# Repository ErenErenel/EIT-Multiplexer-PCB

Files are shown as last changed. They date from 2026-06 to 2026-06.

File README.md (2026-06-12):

# EIT Multiplexer PCB

EE499 Capstone Project — Low-power analog multiplexer board for Electrical Impedance Tomography (EIT).

## Overview

This board drives a 16-channel analog multiplexer (ADG1606) controlled by an RP2040 microcontroller. It is designed for EIT data acquisition, where the multiplexer selects electrode channels to inject current and measure voltage.

**Key ICs:**
- Raspberry Pi RP2040 — microcontroller
- ADG1606 — 16:1 analog multiplexer
- AP2112K — 5V to 3.3V LDO regulator
- LM27761 — negative voltage converter (for symmetric supply)

## Repository Structure

```
Hardware/         — KiCad project files (.kicad_pro, .kicad_sch, .kicad_pcb)
                    Custom footprint and symbol libraries bundled for portability
Production/
  Gerbers/        — Gerber files + drill files ready for PCB fabrication
  BOM/            — Bill of Materials (CSV and XLSX)
Docs/             — Schematic PDF, assembly drawing, component datasheets
```

## Opening the Design

1. Open **KiCad** (v7 or later)
2. Open `Hardware/EIT_Multiplexer.kicad_pro`
3. All custom libraries load automatically via relative paths — no manual configuration needed

## Fabrication

Gerber files are in `Production/Gerbers/`. The board is 2-layer FR4. Upload the contents of that folder (or `EIT_Multiplexer-job.gbrjob`) to your preferred PCB fab (JLCPCB, PCBWay, OSH Park, etc.).

## License

Hardware design files licensed under [CERN Open Hardware Licence v2 – Strongly Reciprocal (CERN-OHL-S)](LICENSE).

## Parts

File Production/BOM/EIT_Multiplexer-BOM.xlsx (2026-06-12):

EIT Multiplexer — Bill of Materials
Item | Qty | Reference | Value | Voltage | Size | Dielectric / Notes | Tolerance | Manufacturer | Manuf. Part # | Description
Resistors
1 | 2 | R1, R5 | 1kΩ |  | 0402 |  | 1% | Yageo | RC0402FR-071KP | RES SMD 1K OHM 1% 1/16W 0402
2 | 2 | R2, R6 | 10kΩ |  | 0402 |  | 1% | Yageo | RC0402FR-0710KP | RES SMD 10K OHM 1% 1/16W 0402
3 | 2 | R3, R4 | 27Ω |  | 0402 |  | 1% | Yageo | RC0402FR-0727RL | RES SMD 27 OHM 1% 1/16W 0402
4 | 2 | R_INVERT1, R_INVERT2 | TBD |  | 0805 |  |  |  |  | Invert resistors — value TBD
Capacitors
5 | 2 | C2, C3 | 15pF | 50V | 0402 | C0G | 5% | Murata | GCM1555C1H150JA16D | CAP CER 15PF 50V C0G/NP0 0402
6 | 10 | C5,C6,C7,C9,C11,C12,C13,C14,C15,C16 | 100nF | 25V | 0402 | X7R | 10% | Murata | GRM155R71E104KE14J | CAP CER 0.1UF 25V X7R 0402
7 | 2 | C8, C10 | 1µF | 10V | 0402 | X6S | 10% | Murata | GRM155C81A105KA12D | CAP CER 1UF 10V X6S 0402
8 | 2 | C1, C4 | 10µF | 16V | 0805 | X5R | 10% | Murata | GRM21BR61C106KE15K | CAP CER 10UF 16V X5R 0805
9 | 8 | C17,C22,C23,C24,C25,C26,C27,C28 | 100nF | 25V | 0805 | X7R | 10% |  |  | CAP CER 0.1UF 25V X7R 0805 — bypass for mux ICs
10 | 2 | C18, C20 | 4.7µF | 10V | 0805 | X5R | 10% |  |  | CAP CER 4.7UF 10V X5R 0805
11 | 1 | C19 | 1µF | 16V | 0805 | X5R | 10% |  |  | CAP CER 1UF 16V X5R 0805
12 | 1 | C21 | 2.2µF | 10V | 0805 | X5R | 10% |  |  | CAP CER 2.2UF 10V X5R 0805
ICs
13 | 1 | U1 | NCP1117-3.3 |  | SOT-223-3 |  |  | ON Semiconductor | NCP1117ST33T3G | IC REG LINEAR 3.3V 1A SOT223
14 | 1 | U2 | W25Q128JVS |  | SOIC-8 |  |  | Winbond | W25Q128JVSIQ TR | IC FLASH 128M SPI 133MHZ 8SOIC
15 | 1 | U3 | RP2040 |  | QFN-56 |  |  | Raspberry Pi | RP2040 | MCU ARM Cortex-M0+ dual-core 133MHz QFN56
16 | 1 | U4 | LM27761DSGR |  | DSG-8 |  |  | Texas Instruments | LM27761DSGR | IC CONV DC/DC NEG 200MA 8WSON
17 | 4 | U5, U6, U7, U8 | ADG1606BCPZ-REEL7 |  | CP-32-2 |  |  | Analog Devices | ADG1606BCPZ-REEL7 | IC MUX 16:1 SINGLE 32LFCSP
Crystal
18 | 1 | Y1 | 12MHz ABM8-272-T3 |  | SMD 3225 |  |  | Abracon | ABM8-272-T3 | CRYSTAL 12.0000MHZ 3.2x2.5MM SMD
Connectors
19 | 1 | J1 | USB Micro-B |  |  |  |  | Amphenol | 10103594-0001LF | CONN RCPT USB2.0 MICRO B SMD R/A
20 | 1 | J2 | 1x16 pin socket |  | 2.54mm |  |  |  |  | Pin socket 1x16 2.54mm vertical
Switches
21 | 2 | SW1, SW2 | Pushbutton |  |  |  |  |  |  | Tactile push button SMD
Test Points
22 | 8 | GND(x4), I+, I-, V+, V- | Test Point |  | THT D2mm |  |  |  |  | THT test point pad D2.0mm drill 1.0mm
Mechanical
23 | 4 | H1, H2, H3, H4 | Mounting Hole |  | M2.5 |  |  |  |  | Mounting hole M2.5

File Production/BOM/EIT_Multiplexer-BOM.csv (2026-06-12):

Id | Designator | Footprint | Quantity | Designation | Supplier and ref
1 | R_INVERT2,R_INVERT1 | R_0805_2012Metric | 2 | R
2 | GND,I+,GND,I-,GND,V+,GND,V- | TestPoint_THTPad_D2.0mm_Drill1.0mm | 8 | Conn_01x01_Pin
3 | C4,C1 | C_0805_2012Metric | 2 | 10u
4 | J1 | USB_Micro-B_Amphenol_10103594-0001LF_Horizontal_modified | 1 | USB_B_Micro
5 | C10,C8 | C_0402_1005Metric | 2 | 1u
6 | C13,C5,C9,C12,C14,C7,C11,C16,C6,C15 | C_0402_1005Metric | 10 | 100n
7 | R2,R6 | R_0402_1005Metric | 2 | 10k
8 | U1 | SOT-223-3_TabPin2 | 1 | NCP1117-3.3_SOT223
9 | U2 | SOIC-8_5.3x5.3mm_P1.27mm | 1 | W25Q128JVS
10 | R1,R5 | R_0402_1005Metric | 2 | 1k
11 | R3,R4 | R_0402_1005Metric | 2 | 27
12 | U3 | RP2040-QFN-56 | 1 | RP2040
13 | U4 | DSG0008A | 1 | LM27761DSGR
14 | C18,C20 | C_0805_2012Metric | 2 | 4.7u
15 | C23,C26,C22,C25,C24,C28,C17,C27 | C_0805_2012Metric | 8 | 100n
16 | H3,H2,H4,H1 | MountingHole_2.7mm_M2.5 | 4 | MountingHole
17 | C2,C3 | C_0402_1005Metric | 2 | 15p
18 | C21 | C_0805_2012Metric | 1 | 2.2u
19 | C19 | C_0805_2012Metric | 1 | 1u
20 | SW2,SW1 | pushbutton (1) | 2 | SW_Push
21 | Y1 | Crystal_SMD_3225-4Pin_3.2x2.5mm | 1 | ABM8-272-T3
22 | U8,U7,U5,U6 | CP_32_2_ADI | 4 | ADG1606BCPZ-REEL7
23 | J2 | PinSocket_1x16_P2.54mm_Vertical | 1 | Conn_01x16_Pin

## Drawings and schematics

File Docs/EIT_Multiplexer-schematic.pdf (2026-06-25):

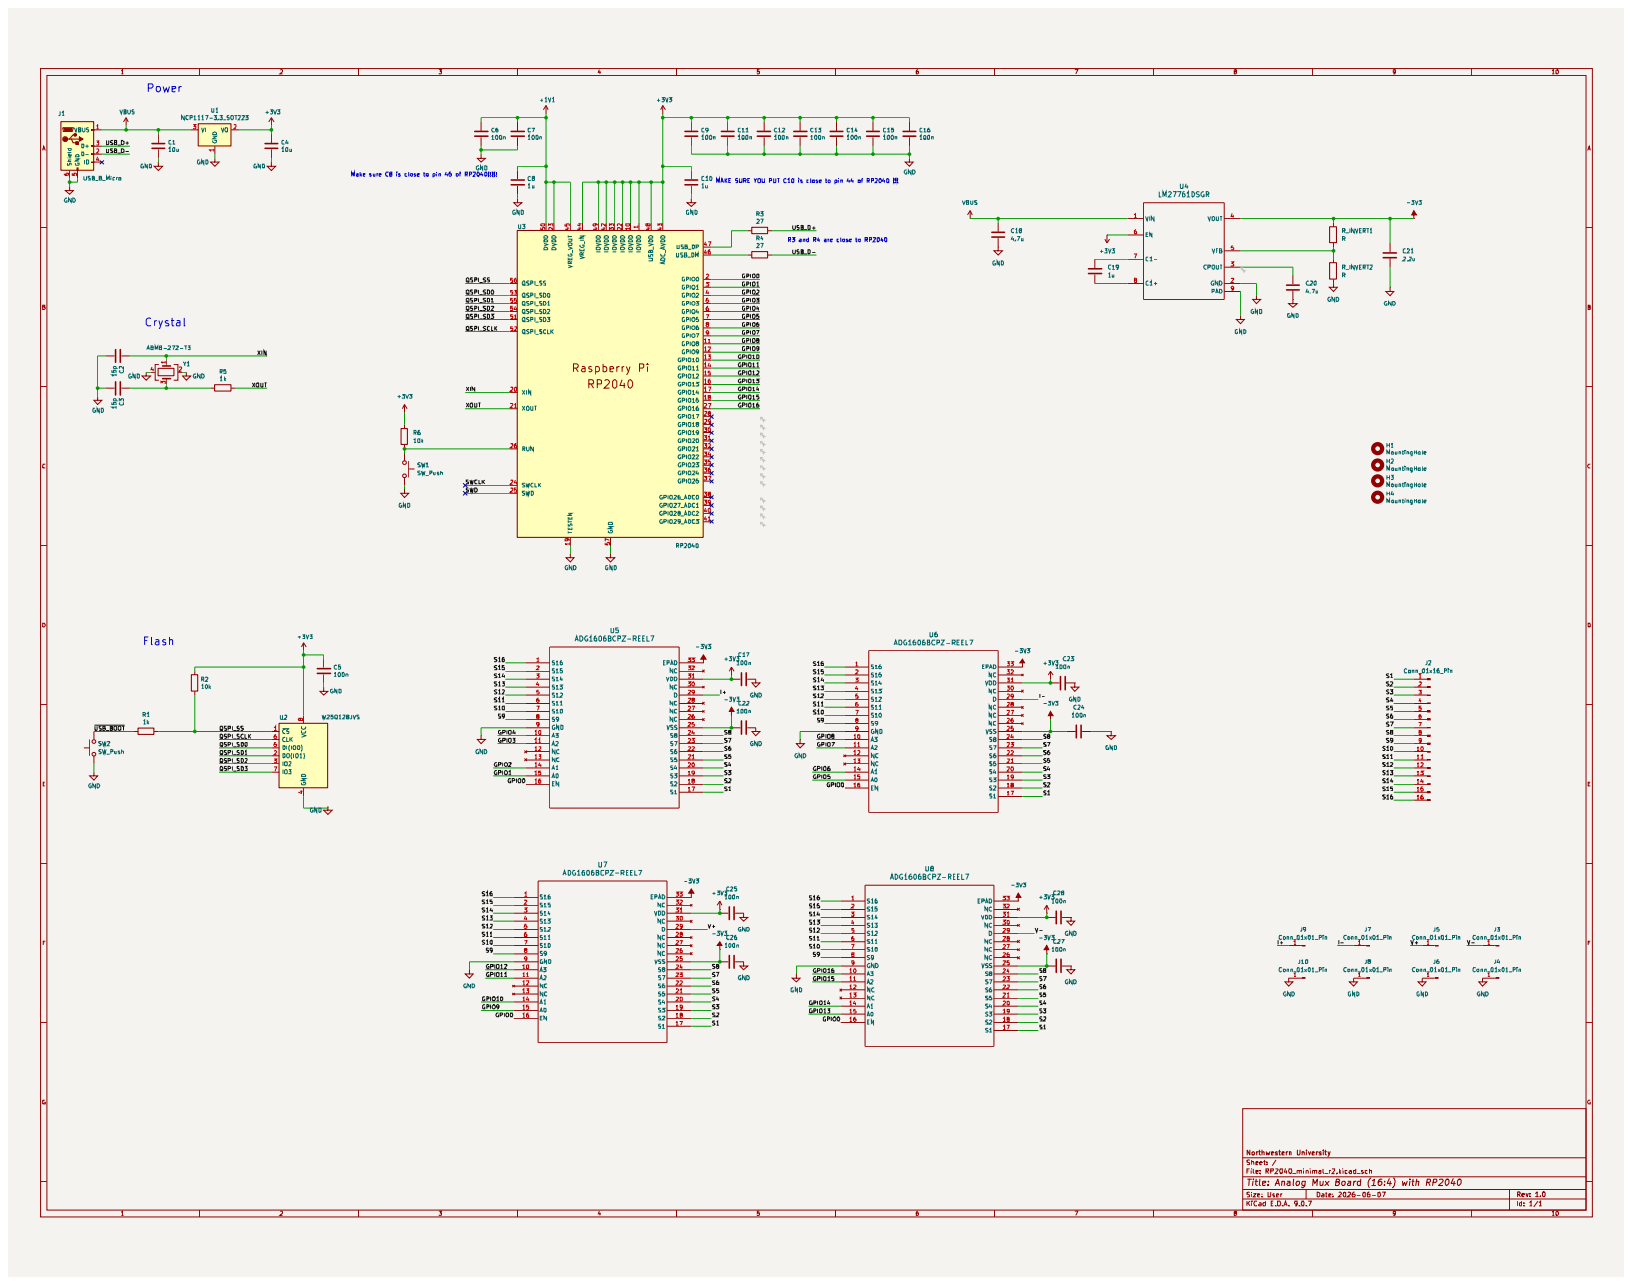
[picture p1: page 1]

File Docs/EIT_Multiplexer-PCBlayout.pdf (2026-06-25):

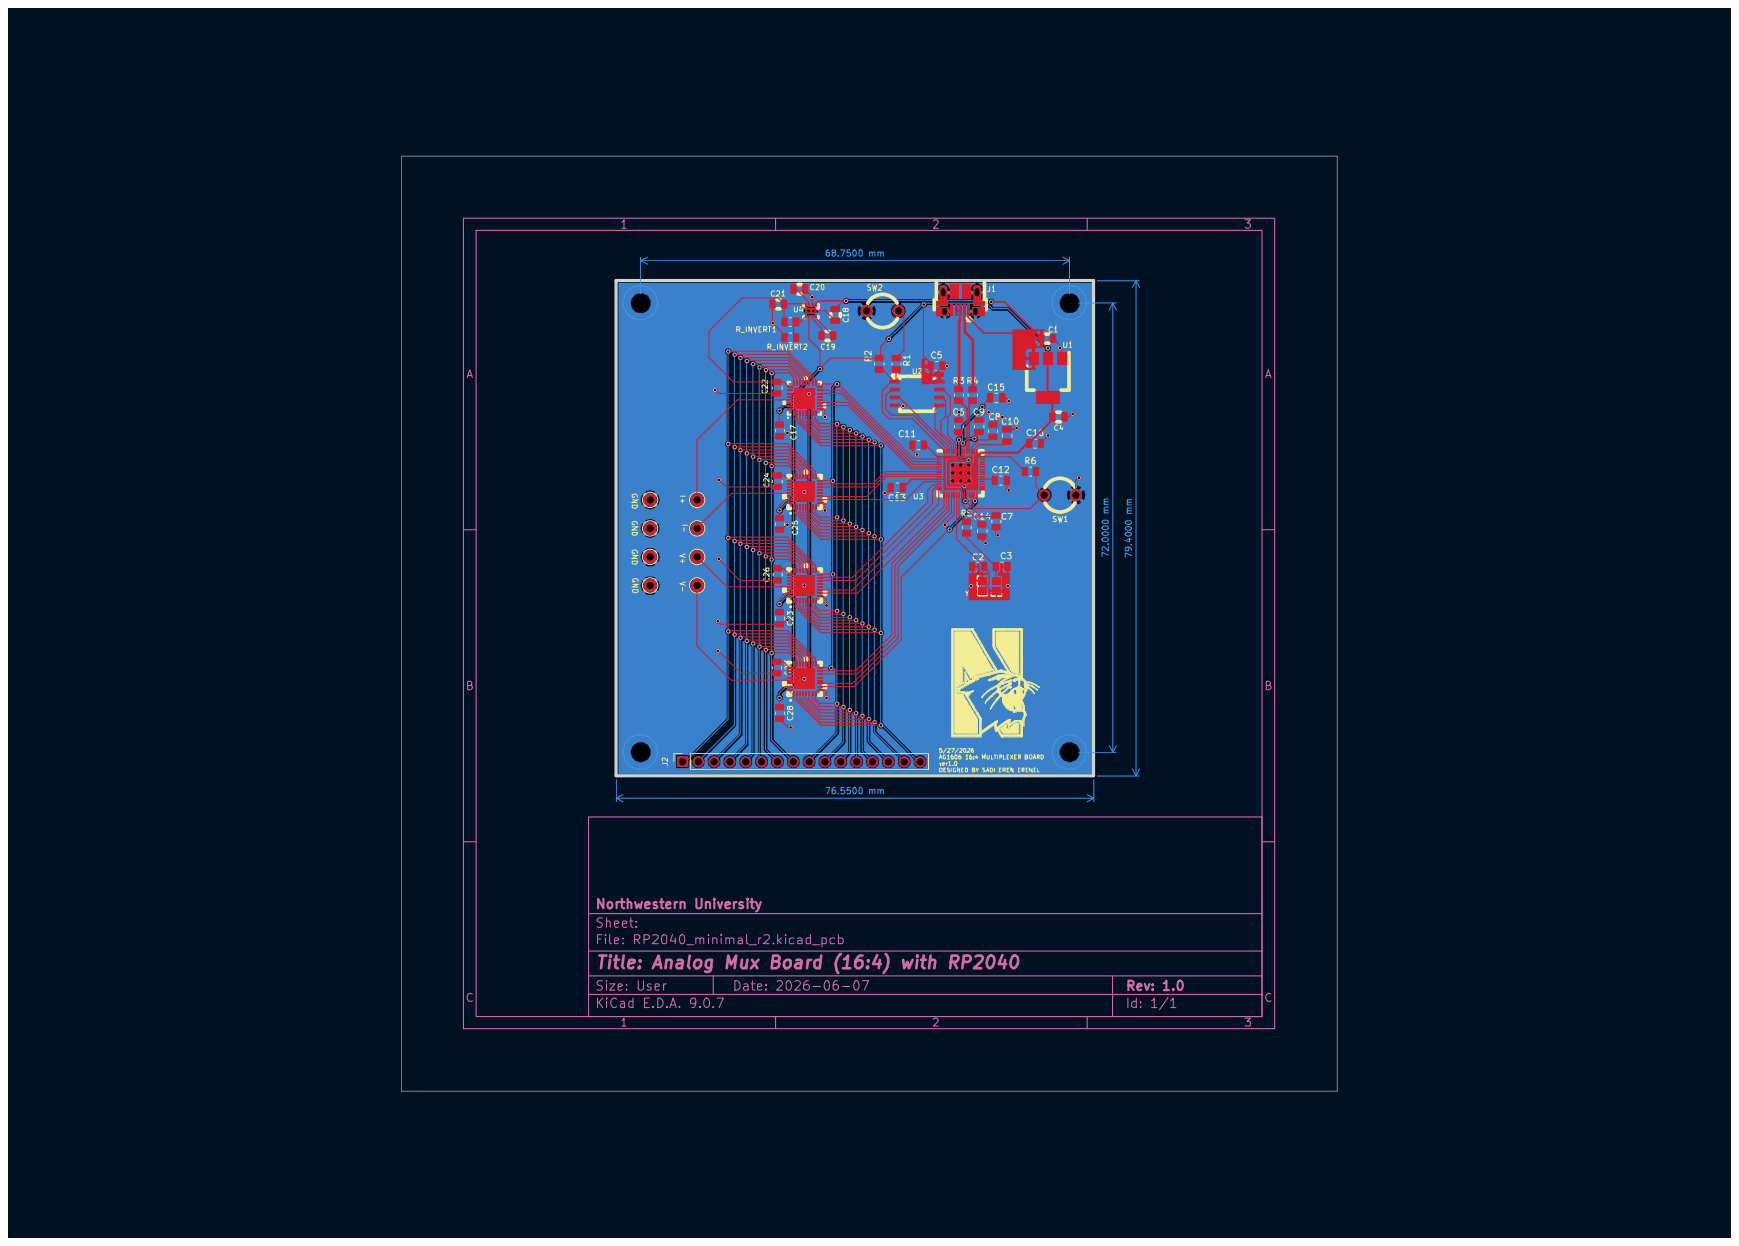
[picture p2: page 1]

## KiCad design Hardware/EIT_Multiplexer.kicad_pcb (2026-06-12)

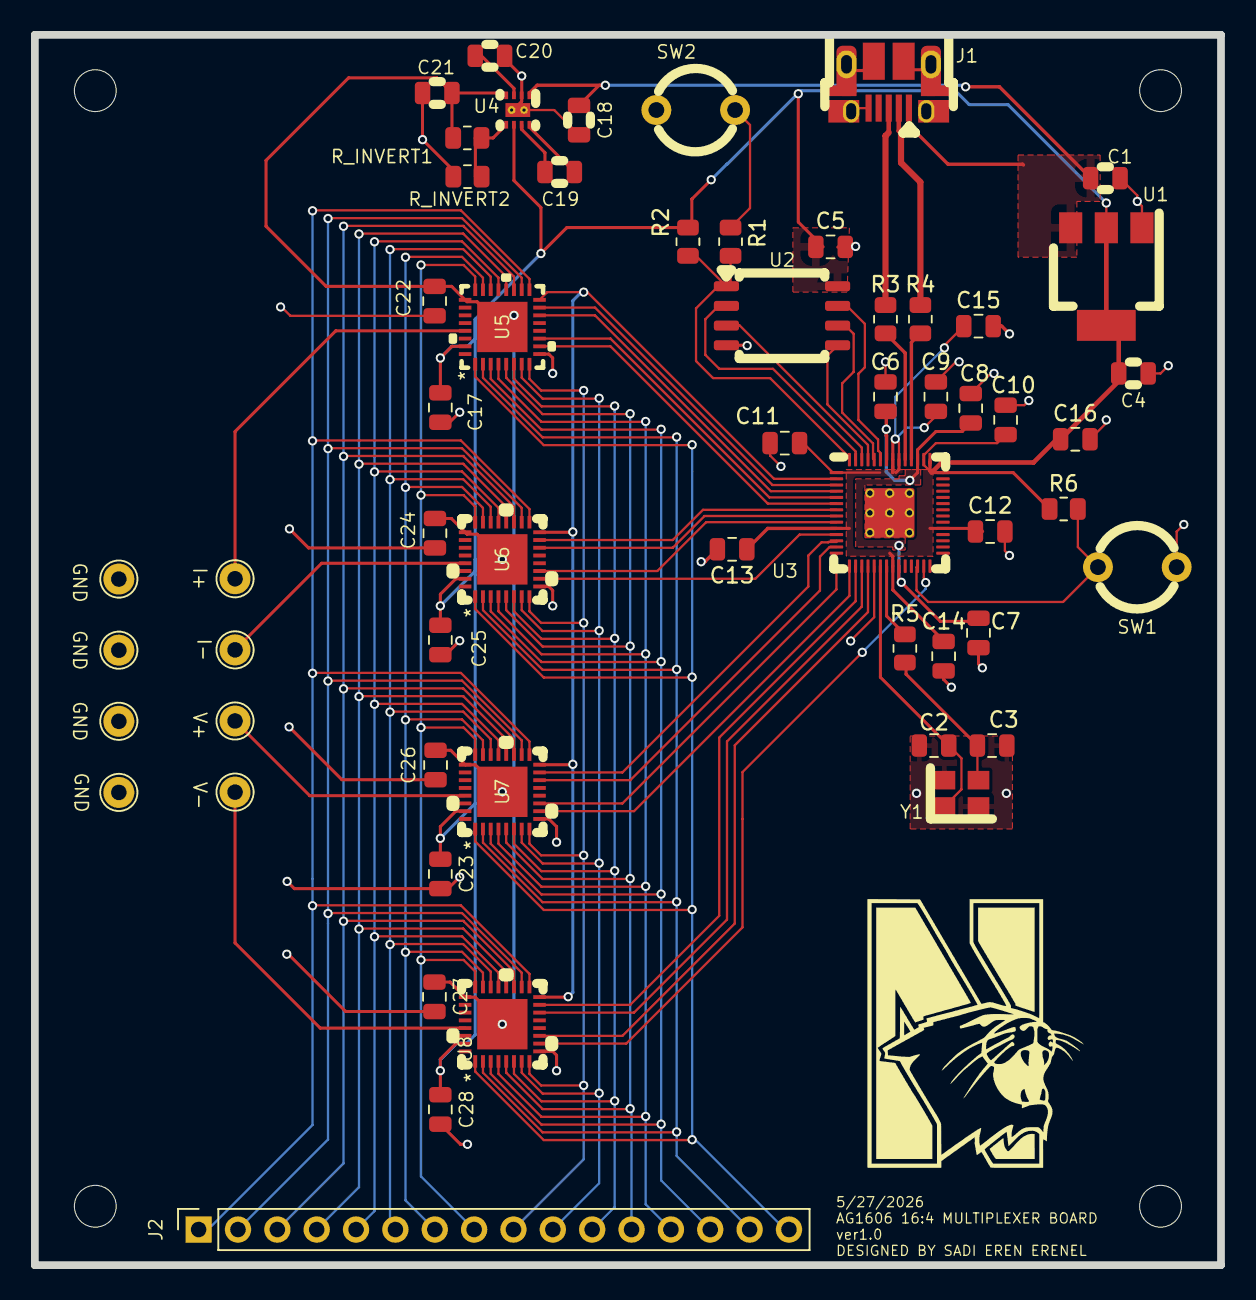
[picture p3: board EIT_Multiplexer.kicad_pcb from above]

Board: 2 copper layers, 76.5 x 79.4 mm, 61 parts (0 on the bottom side), 61 nets.

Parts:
C1, C4: 10u; C_0805_2012Metric
C2, C3: 15p; C_0805_2012Metric
C5, C6, C7, C9, C11, C12, C13, C14, C15, C16, C17, C22, C23, C24, C25, C26, C27, C28: 100n; C_0805_2012Metric
C8, C10, C19: 1u; C_0805_2012Metric
C18, C20: 4.7u; C_0805_2012Metric
C21: 2.2u; C_0805_2012Metric
GND: Conn_01x01_Pin; TestPoint_THTPad_D2.0mm_Drill1.0mm
GND#2, GND#3, GND#4: Conn_01x01_Pin; TestPoint_THTPad_D2.0mm_Drill1.0mm
H1, H2, H3, H4: MountingHole; MountingHole_2.7mm_M2.5
I+: Conn_01x01_Pin; TestPoint_THTPad_D2.0mm_Drill1.0mm
I-: Conn_01x01_Pin; TestPoint_THTPad_D2.0mm_Drill1.0mm
J1: USB_B_Micro; USB_Micro-B_Amphenol_10103594-0001LF_Horizontal_modified
J2: Conn_01x16_Pin; PinSocket_1x16_P2.54mm_Vertical
R1, R5: 1k; R_0805_2012Metric
R2, R6: 10k; R_0805_2012Metric
R3, R4: 27; R_0805_2012Metric
R_INVERT1, R_INVERT2: R; R_0805_2012Metric
SW1, SW2: SW_Push; pushbutton (1)
U1: NCP1117-3.3_SOT223; SOT-223-3_TabPin2
U2: W25Q128JVS; SOIC-8_5.3x5.3mm_P1.27mm
U3: RP2040; RP2040-QFN-56
U4: LM27761DSGR; DSG0008A
U5, U6, U7, U8: ADG1606BCPZ-REEL7; CP_32_2_ADI
V+: Conn_01x01_Pin; TestPoint_THTPad_D2.0mm_Drill1.0mm
V-: Conn_01x01_Pin; TestPoint_THTPad_D2.0mm_Drill1.0mm
Y1: ABM8-272-T3; Crystal_SMD_3225-4Pin_3.2x2.5mm

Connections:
+1V1: C6.1, C7.1, C8.1, U3.23 (DVDD), U3.45 (VREG_VOUT), U3.50 (DVDD)
+3V3: C4.1, C5.1, C9.1, C10.1, C11.1, C12.1, C13.1, C14.1, C15.1, C16.1, C17.1, C23.1, C25.1, C28.1, R2.1, R6.1, U1.2 (VO), U2.8 (VCC), U3.1 (IOVDD), U3.10 (IOVDD), U3.22 (IOVDD), U3.33 (IOVDD), U3.42 (IOVDD), U3.43 (ADC_AVDD), U3.44 (VREG_IN), U3.48 (USB_VDD), U3.49 (IOVDD), U4.6 (EN), U5.31 (VDD), U6.31 (VDD), U7.31 (VDD), U8.31 (VDD)
-3V3: C21.1, C22.1, C24.1, C26.1, C27.1, R_INVERT1.1, U4.4 (VOUT), U5.25 (VSS), U5.33 (EPAD), U6.25 (VSS), U6.33 (EPAD), U7.25 (VSS), U7.33 (EPAD), U8.25 (VSS), U8.33 (EPAD)
/GPIO0: U3.2 (GPIO0), U5.16 (EN), U6.16 (EN), U7.16 (EN), U8.16 (EN)
/GPIO1: U3.3 (GPIO1), U5.15 (A0)
/GPIO2: U3.4 (GPIO2), U5.14 (A1)
/GPIO3: U3.5 (GPIO3), U5.11 (A2)
/GPIO4: U3.6 (GPIO4), U5.10 (A3)
/GPIO5: U3.7 (GPIO5), U6.15 (A0)
/GPIO6: U3.8 (GPIO6), U6.14 (A1)
/GPIO7: U3.9 (GPIO7), U6.11 (A2)
/GPIO8: U3.11 (GPIO8), U6.10 (A3)
/GPIO9: U3.12 (GPIO9), U7.15 (A0)
/GPIO10: U3.13 (GPIO10), U7.14 (A1)
/GPIO11: U3.14 (GPIO11), U7.11 (A2)
/GPIO12: U3.15 (GPIO12), U7.10 (A3)
/GPIO13: U3.16 (GPIO13), U8.15 (A0)
/GPIO14: U3.17 (GPIO14), U8.14 (A1)
/GPIO15: U3.18 (GPIO15), U8.11 (A2)
/GPIO16: U3.27 (GPIO16), U8.10 (A3)
/I+: I+.1, U5.29 (D)
/I-: I-.1, U6.29 (D)
/QSPI_SCLK: U2.6 (CLK), U3.52 (QSPI_SCLK)
/QSPI_SD0: U2.5 (DI(IO0)), U3.53 (QSPI_SD0)
/QSPI_SD1: U2.2 (DO(IO1)), U3.55 (QSPI_SD1)
/QSPI_SD2: U2.3 (IO2), U3.54 (QSPI_SD2)
/QSPI_SD3: U2.7 (IO3), U3.51 (QSPI_SD3)
/QSPI_SS: R1.1, R2.2, U2.1 (~CS), U3.56 (QSPI_SS)
/S1: J2.1, U5.17 (S1), U6.17 (S1), U7.17 (S1), U8.17 (S1)
/S2: J2.2, U5.18 (S2), U6.18 (S2), U7.18 (S2), U8.18 (S2)
/S3: J2.3, U5.19 (S3), U6.19 (S3), U7.19 (S3), U8.19 (S3)
/S4: J2.4, U5.20 (S4), U6.20 (S4), U7.20 (S4), U8.20 (S4)
/S5: J2.5, U5.21 (S5), U6.21 (S5), U7.21 (S5), U8.21 (S5)
/S6: J2.6, U5.22 (S6), U6.22 (S6), U7.22 (S6), U8.22 (S6)
/S7: J2.7, U5.23 (S7), U6.23 (S7), U7.23 (S7), U8.23 (S7)
/S8: J2.8, U5.24 (S8), U6.24 (S8), U7.24 (S8), U8.24 (S8)
/S9: J2.9, U5.8 (S9), U6.8 (S9), U7.8 (S9), U8.8 (S9)
/S10: J2.10, U5.7 (S10), U6.7 (S10), U7.7 (S10), U8.7 (S10)
/S11: J2.11, U5.6 (S11), U6.6 (S11), U7.6 (S11), U8.6 (S11)
/S12: J2.12, U5.5 (S12), U6.5 (S12), U7.5 (S12), U8.5 (S12)
/S13: J2.13, U5.4 (S13), U6.4 (S13), U7.4 (S13), U8.4 (S13)
/S14: J2.14, U5.3 (S14), U6.3 (S14), U7.3 (S14), U8.3 (S14)
/S15: J2.15, U5.2 (S15), U6.2 (S15), U7.2 (S15), U8.2 (S15)
/S16: J2.16, U5.1 (S16), U6.1 (S16), U7.1 (S16), U8.1 (S16)
/USB_D+: J1.3 (D+), R3.1
/USB_D-: J1.2 (D-), R4.1
/V+: U7.29 (D), V+.1
/V-: U8.29 (D), V-.1
/XIN: C2.1, U3.20 (XIN), Y1.1
/XOUT: R5.1, U3.21 (XOUT)
/~USB_BOOT: R1.2, SW2.2
GND: C1.2, C2.2, C3.2, C4.2, C5.2, C6.2, C7.2, C8.2, C9.2, C10.2, C11.2, C12.2, C13.2, C14.2, C15.2, C16.2, C17.2, C18.2, C20.2, C21.2, C22.2, C23.2, C24.2, C25.2, C26.2, C27.2, C28.2, GND.1, GND#2.1, GND#3.1, GND#4.1, J1.5 (GND), J1.6 (Shield), R_INVERT2.2, SW1.2, SW2.1, U1.1 (GND), U2.4 (GND), U3.19 (TESTEN), U3.57 (GND), U4.2 (GND), U4.9 (PAD), U4.V, U5.9 (GND), U6.9 (GND), U7.9 (GND), U8.9 (GND), Y1.2, Y1.4
unnamed: C3.1, R5.2, Y1.3
unnamed: R6.2, SW1.1, U3.26 (RUN)
unnamed: R4.2, U3.46 (USB_DM)
unnamed: R3.2, U3.47 (USB_DP)
unnamed: C19.2, U4.8 (C1+)
unnamed: C19.1, U4.7 (C1-)
unnamed: C20.1, U4.3 (CPOUT)
unnamed: R_INVERT1.2, R_INVERT2.1, U4.5 (VFB)
VBUS: C1.1, C18.1, J1.1 (VBUS), U1.3 (VI), U4.1 (VIN)

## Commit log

2026-06-12 Initial commit: EIT Multiplexer PCB design files
    KiCad project for EE499 capstone — 16-channel ADG1606 multiplexer board
    with RP2040 microcontroller for Electrical Impedance Tomography.
    Includes: KiCad source files, bundled custom libraries, Gerbers, BOM, and docs.
    [EIT_Multiplexer-BOM.csv, EIT_Multiplexer-BOM.xlsx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]
2026-06-12 Update Excel BOM to match KiCad CSV export
    Added missing components: 4x ADG1606, LM27761, 100nF 0805 bypass caps,
    4.7uF caps, test points, mounting holes, push buttons, corrected connector.
    Removed stale J3/J4 headers from old revision. Kept manufacturer part
    numbers from original Excel where designators matched.
    [EIT_Multiplexer-BOM.xlsx]
2026-06-25 Replace schematic and PCB layout PDFs with correct final versions
2026-06-25 Remove datasheets and assembly PDF from Docs
